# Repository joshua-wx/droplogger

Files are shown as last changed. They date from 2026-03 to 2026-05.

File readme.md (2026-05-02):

# Drop Logger — User Guide



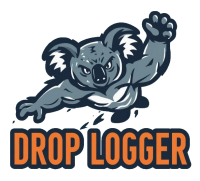
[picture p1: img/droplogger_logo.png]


## Table of Contents

- [Overview](#overview)
- [Power](#power)
- [Hardware Connections](#hardware-connections)
- [Sensor Specifications and Calibration](#sensor-specifications-and-calibration)
  - [BMP581 — Barometric Pressure](#bmp581--barometric-pressure)
  - [ICM20649 — Accelerometer and Gyroscope](#icm20649--accelerometer-and-gyroscope)
  - [ISM330DHCX — Accelerometer and Gyroscope](#ism330dhcx--accelerometer-and-gyroscope)
  - [Accelerometer Calibration](#accelerometer-calibration)
  - [Implications for Drop Experiments](#implications-for-drop-experiments)
- [Device Modes](#device-modes)
  - [Fall Detection](#fall-detection)
- [Data Logging](#data-logging)
  - [Starting a Log](#starting-a-log)
  - [Stopping a Log](#stopping-a-log)
  - [Output Files](#output-files)
  - [Binary File Format](#binary-file-format)
- [Downloading Data](#downloading-data)
  - [Option 1: WiFi File Server (Recommended)](#option-1-wifi-file-server-recommended)
  - [Option 2: USB (via serial tools)](#option-2-usb-via-serial-tools)
- [Converting Binary Files to CSV](#converting-binary-files-to-csv)
  - [CSV File Format](#csv-file-format)
- [Configuration](#configuration)
  - [Device Name](#device-name)
  - [IMU Selection](#imu-selection)
  - [Fall Detection Sensitivity](#fall-detection-sensitivity)
- [Code Overview — `drop_logger.py`](#code-overview--drop_loggerpy)
  - [Sensor Initialisation](#sensor-initialisation)
  - [The Logging Loop](#the-logging-loop)
  - [Key Variables You Might Want to Change](#key-variables-you-might-want-to-change)
- [File Structure Summary](#file-structure-summary)
- [Evaluating Data](#evaluating-data)
- [Python tests](#tests)
- [About](#about)
---

## Overview

The Drop Logger is an ESP32-S3-based data logger designed to record barometric pressure, acceleration, and gyroscope data at high frequency (approx every 3 ms). It uses two sensors over I2C:

- **BMP581** — barometric pressure sensor (records pressure difference from a reference taken at startup)
- **ICM20649** or **ISM330DHCX** — 6-axis accelerometer and gyroscope (records acceleration magnitude in m/s² and 3-axis rotation in °/s). The active IMU is selected via a config file — see [IMU Selection](#imu-selection).

The device is designed to be mounted inside a 3D-printed hailstone and dropped from a drone at heights of 100+ m. The recorded data allows characterisation of tumbling motions and fall dynamics of non-spherical hailstones.

The device logging is controlled entirely with the **Mode/Boot button** (GPIO 0) and provides feedback through an **onboard blue LED** (GPIO 2).

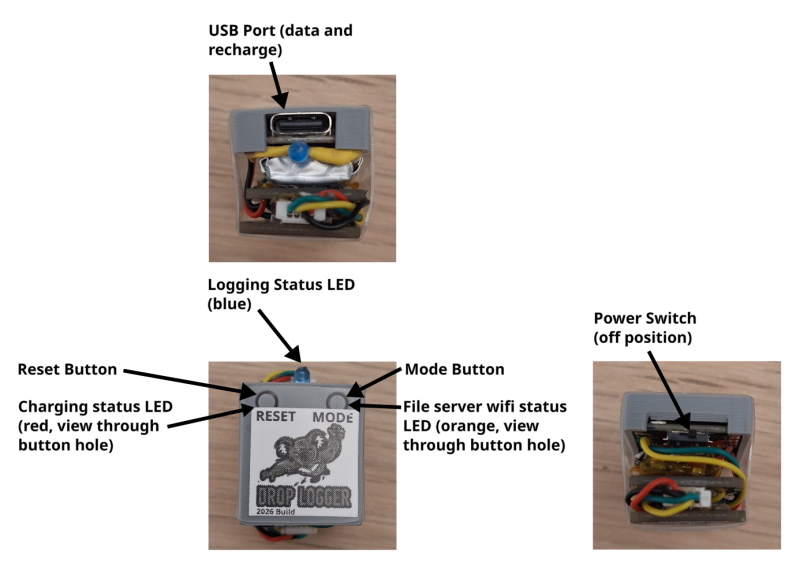
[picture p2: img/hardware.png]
hardware


---
## Power

The drop logger uses a permanently connected 3.7V 180mah lithium polymer battery. A fully charged battery will power the logger for at least 1 hour (e.g., 2-3 full flights).

To turn on the device, slide the switch towards the left side of the device (when viewing the logo from the front). The device will also be powered by usb regardless of the switch position.

To charge the battery, connect via usb when the power is switched on. A small red led will start flashing during charging and turn off when charging is completed. Charging takes approximately 1 hour to complete.

---

## Hardware Connections

| Component | ESP32-S3 Pin |
|---|---|
| I2C SCL | GPIO 6 |
| I2C SDA | GPIO 5 |
| BLUE LED | GPIO 2 |
| BOOT/MODE button | GPIO 0 |
| BMP581 address | 0x47 |
| ICM20649 address | 0x68 |
| ISM330DHCX address | 0x6A |

---

## Sensor Specifications and Calibration
  
### BMP581 — Barometric Pressure
 
The BMP581 is a 24-bit absolute barometric pressure sensor from Bosch Sensortec. It provides on-chip linearization and temperature compensation.
 
**Datasheet specifications:**
 
| Parameter | Value |
|---|---|
| Pressure operating range | 300–1250 hPa |
| Absolute accuracy (typical) | ±0.3 hPa (~±2.5 m altitude) |
| Absolute accuracy (max) | ±0.5 hPa (~±4 m altitude) |
| Relative accuracy (900-1100hPa) | ±0.4 Pa (~±0.033 m altitude) |
| Pressure resolution | 1/64 Pa (0.015625 Pa) |
| RMS noise (typical) | 0.08 Pa at 1000 hPa |
| Temperature coefficient offset | ±0.5 Pa/K (typical) |
| Long-term drift | ±0.1 hPa over 12 months |
| Temperature accuracy | ±0.5 °C |
| Maximum output data rate | up to 240 Hz (OSR×1) |
 
**Logger configuration:** The logger uses the fastest possible settings — OSR×1 for both pressure and temperature, with the IIR filter disabled (`COEF_0`). This maximises sample rate at the cost of higher per-sample noise. The noise specifications above are typical values; at OSR×1 with no filtering, individual samples will be noisier than the best-case figures. Higher oversampling (e.g. OSR×128) reduces noise dramatically but slows the output data rate.

### ICM20649 — Accelerometer and Gyroscope
 
The ICM20649 is a wide-range 6-axis MEMS inertial measurement unit from TDK InvenSense, designed for high-impact and high-speed rotation applications. It features a 16-bit ADC for each axis.
 
**Datasheet specifications:**
 
| Parameter | Value |
|---|---|
| Accelerometer full-scale ranges | ±4g, ±8g, ±16g, ±30g |
| Accelerometer sensitivity error | ±0.5% |
| Accelerometer noise density | 285 µg/√Hz |
| Gyroscope full-scale ranges | ±500, ±1000, ±2000, ±4000 °/s |
| Gyroscope sensitivity error | ±0.5% |
| Gyroscope noise density | 0.0175 °/s/√Hz |
| ADC resolution | 16-bit per axis |
| Operating temperature range | −40 to +85 °C |
 
**Logger configuration:** The accelerometer is set to ±8g and the gyroscope to ±4000 °/s. At the ±8g range, the raw sensitivity is 4096 LSB/g, giving a per-axis resolution of approximately 0.0024 m/s². At the ±4000 °/s gyroscope range, the sensitivity is 8.2 LSB/°/s, giving a resolution of approximately 0.12 °/s per axis. The ±8g accelerometer range is sufficient for freefall (~0g) through to aerodynamic deceleration, while the ±4000 °/s gyro range accommodates the fast tumbling expected during drop experiments.

### ISM330DHCX — Accelerometer and Gyroscope

The ISM330DHCX is a 6-axis MEMS IMU from STMicroelectronics. It is pin- and interface-compatible with the ICM20649 driver used in this project — the same `.acceleration` and `.gyro` properties are exposed, so no changes to the logging loop are required when switching between the two sensors.

**Datasheet specifications:**

| Parameter | Value |
|---|---|
| Accelerometer full-scale ranges | ±2g, ±4g, ±8g, ±16g |
| Accelerometer sensitivity error | ±1.5% |
| Accelerometer noise density | 70 µg/√Hz |
| Gyroscope full-scale ranges | ±125, ±250, ±500, ±1000, ±2000, ±4000 °/s |
| Gyroscope sensitivity error | ±1.5% |
| Gyroscope noise density | 0.007 °/s/√Hz |
| ADC resolution | 16-bit per axis |
| Operating temperature range | −40 to +105 °C |

**Logger configuration:** The accelerometer is set to ±8g and the gyroscope to ±4000 °/s at 208 Hz output data rate, matching the ICM20649 logging configuration. The `test_board.py` script uses ±1000 °/s for bench verification where fast rotation is unlikely.

### Accelerometer Calibration
 
The logger applies a simple scale correction to the acceleration magnitude to compensate for sensor bias. The correction factor is computed as:
 
```
accel_scale_correction = 9.80665 / a_mag_at_rest
```
 
where `a_mag_at_rest` is the measured acceleration magnitude when the sensor is stationary (currently set to 10.21 m/s² in `config/accel_calibration.txt`). The expected value at rest is 1g (9.80665 m/s²), so the correction factor (~0.960) scales all magnitude readings to compensate for the consistent offset. This is a first-order correction that assumes the bias is uniform across all axes and magnitudes. It does not correct for per-axis offset, cross-axis sensitivity, or nonlinearity.
 
**The value of `a_mag_at_rest` stored in `config/accel_calibration.txt` should be recalibrated for each individual sensor unit, as the offset varies from device to device.**
 
### Implications for Drop Experiments
 
For typical drop experiments from 100+ m, the key measurement considerations are:
 
**Pressure/altitude:** The relative accuracy of ±0.04 Pa (~±0.033 m) is more than adequate for tracking altitude changes of 100–250 m. However, the absolute accuracy of ±0.3 hPa (~±2.5 m) means the starting altitude cannot be determined to better than a few metres from pressure alone. The OSR×1 setting with no IIR filter means individual pressure samples will be noisy, but post-processing (e.g. a moving average) can smooth this out without affecting the overall altitude profile.
 
**Acceleration:** During freefall the sensor should read close to 0g (limited by aerodynamic drag on the hailstone). The ±8g range provides headroom for launch accelerations and impact events. The 0.01 m/s² recorded resolution is sufficient to distinguish freefall from rest.
 
**Gyroscope:** The ±4000 °/s range covers up to ~11 full rotations per second, which is expected to be sufficient for moderate tumbling. The 1 °/s integer resolution in the recorded data is adequate for characterising tumble rates and their evolution during the fall.

---

## Device Modes

On power-up the device enters a waiting state and continuously monitors the accelerometer. There are three ways to proceed:

| Trigger | Action | BLUE LED Feedback |
|---|---|---|
| **Fall detected** | Logging starts automatically | Blue LED on |
| **Short MODE button press** (<2 s) | Logging starts manually | Single flash, then Blue LED on |
| **Long MODE button press** (≥2 s) | WiFi file server starts | Blue LED blinks while held, then triple blink |

### Fall Detection

The device continuously reads the accelerometer and computes total acceleration magnitude (`√(aX² + aY² + aZ²)`). If this value drops below **5 m/s²** for **0.25 s**, the device assumes it is in freefall and starts logging automatically. This means you can power on the device before mounting it in the hailstone, and logging will begin on its own when dropped.

### Reset button

The reset button will restore the logger to the waiting state (but ideally do not use to terminate logging)

---

## Data Logging

### Duration

The total storage for data files is 5.8MB, which is approximately 24 minutes of data with the current binary encoding

### Starting a Log

Logging starts via any of the three triggers described above. Once running, the **Blue LED stays on** to indicate data is being recorded.

### Stopping a Log

Press the **MODE button** at any time to stop recording. The button is checked on every sample iteration:

1. **Press the MODE button** — recording stops immediately.
2. The **Blue LED turns off** and the serial console prints `Finished`.
3. The data file is flushed and closed.

Logging will also stop automatically if free storage drops below ~50 KB.
Frees space for storage is approximate 5.8 MB.

### Output Files

Data files are saved to the `/data/` directory on the ESP32's flash filesystem in binary format. Each run creates a new `.bin` file with an auto-incrementing number using the device name: `droplogger_1.bin`, `droplogger_2.bin`, etc. (or `{device_name}_1.bin` if you've changed the device name).

### Binary File Format

Each file uses the `DL01` binary format, consisting of a header followed by fixed-size data rows.

**Header (8 bytes):**

| Field | Type | Description |
|---|---|---|
| Magic | 4 bytes | `DL01` — format identifier |
| Reference pressure | float32 | Absolute pressure in hPa at startup |

**Row (16 bytes each):**

| Field | Type | Unit | Description |
|---|---|---|---|
| `time_ms` | uint32 | milliseconds | Elapsed time since logging started |
| `p_diff` | int32 | milli-hPa | `(ref_pressure − current_pressure) × 1000`. Positive values mean pressure has decreased (altitude increased). |
| `a_mag` | uint16 | centi-m/s² | Acceleration magnitude × 100 (`√(aX² + aY² + aZ²)`), with a scale correction applied |
| `gX` | int16 | °/s | Rotation rate around X axis (integer) |
| `gY` | int16 | °/s | Rotation rate around Y axis (integer) |
| `gZ` | int16 | °/s | Rotation rate around Z axis (integer) |

All values are big-endian. To reconstruct absolute pressure: `absolute_pressure = ref_pressure − (p_diff / 1000)`.

---

## Downloading Data

There are two ways to get data off the device: over WiFi using the built-in file server, or over USB.

### Option 1: WiFi File Server (Recommended, much much faster)

This is the easiest method and doesn't require any software on your computer beyond a web browser.
Make sure the PC/laptop is within 30 cm of the logger to get a good wifi signal (The logger has no wifi antenna...) 

1. **Power on** the device.
2. **Long-press the MODE button** (hold for ≥2 seconds). The Blue LED will blink while held and then triple-blink to confirm.
3. The device creates a **WiFi access point** named after the device (default: `droplogger`). The password is `hailstone`.
3. Orange LED under the MODE button will be activated.
4. **Connect your phone or laptop** to this WiFi network.
5. **Open a browser** and navigate to `http://192.168.4.1`.
6. You'll see a file listing page where you can **download** or **delete** individual files, or **delete all** files at once.

The device name (and therefore WiFi AP name) is read from `config/device_name.txt` on the ESP32's filesystem. See [Configuration](#configuration) for details.

### Option 2: USB (via serial tools, slow)

Connect to the ESP32-S3 over USB and use one of these tools:

- **Thonny IDE** — Connect to the board, navigate to `/data/` in the file browser, right-click a file and choose "Download to…".
- **mpremote** — `mpremote cp :/data/droplogger_1.bin .`
- **ampy** — `ampy --port /dev/ttyUSB0 get /data/droplogger_1.bin > droplogger_1.bin`

Replace the serial port (`/dev/ttyUSB0`, `COM3`, etc.) as appropriate for your system.

---

## Converting Binary Files to CSV

If you have `.bin` files from the logger (binary format, identified by the `DL01` magic header), you can convert them to CSV on your desktop computer using `unpack_droplogger_binary.py`. This is a standard Python script (not MicroPython) — run it on your PC. It does not require any non-standard Python libraries.

**Basic usage:**

```bash
python desktop-tools/unpack_droplogger_binary.py droplogger_1.bin
```

This produces `droplogger_1.csv` alongside the original file.

**Specify output path:**

```bash
python desktop-tools/unpack_droplogger_binary.py droplogger_1.bin -o output.csv
```

This produces `output.csv`.

**Batch convert a folder:**

```bash
python desktop-tools/unpack_droplogger_binary.py /path/to/folder/
python desktop-tools/unpack_droplogger_binary.py /path/to/folder/ --replace
```

This converts all .bin files in the directory.

### CSV File Format
 
Each output CSV contains a header row, a reference row, and then continuous data rows.
 
**Header:**
 
```
time(s),Pressure Difference(hPa),a(ms^-2),gX(deg/s),gY(deg/s),gZ(deg/s)
```
 
**Reference row:** The first data row has time set to `-0.001` and the second column contains the **absolute reference pressure** in hPa recorded at startup. The remaining columns are empty. This allows you to reconstruct absolute pressure from the differential values in subsequent rows: `absolute_pressure = ref_pressure − pressure_difference`.
 
**Data columns:**
 
| Column | Unit | Description |
|---|---|---|
| `time(s)` | seconds | Elapsed time since logging started (millisecond resolution) |
| `Pressure Difference(hPa)` | hPa | `ref_pressure − current_pressure`. Positive values mean pressure has decreased (altitude increased). |
| `a(ms^-2)` | m/s² | Acceleration magnitude (`√(aX² + aY² + aZ²)`), with scale correction applied |
| `gX(deg/s)` | °/s | Rotation rate around X axis (integer) |
| `gY(deg/s)` | °/s | Rotation rate around Y axis (integer) |
| `gZ(deg/s)` | °/s | Rotation rate around Z axis (integer) |
 
**Example:**
 
```
time(s),Pressure Difference(hPa),a(ms^-2),gX(deg/s),gY(deg/s),gZ(deg/s)
-0.001,1008.234,,,,
0.003,0.012,9.81,0,-1,2
0.006,0.025,9.78,1,0,1
0.009,0.041,9.83,-1,2,0
```
---

## Configuration

### Device Name

The device name is read from a file called `config/device_name.txt` on the ESP32's filesystem. If the file doesn't exist or is empty, the default name `droplogger` is used. This name is used for both the WiFi access point SSID and the binary file naming.

To change the device name, create or edit `config/device_name.txt` on the ESP32 (e.g. via Thonny or mpremote):

```
my-hailstone-1
```

### IMU Selection

The IMU type is read from `config/imu_type.txt` on the ESP32's filesystem. If the file is missing or contains an unrecognised value, the device defaults to `ICM20649`.

To select the ISM330DHCX, create `config/imu_type.txt` containing:

```
ISM330DHCX
```

To revert to the ICM20649, set the file contents to:

```
ICM20649
```

An example file is provided at `config/imu_type.txt.example`. The same setting is read by `main.py`, `drop_logger.py`, and `test_board.py`, so only one file needs to be updated.

### Fall Detection Sensitivity

In `main.py`, these variables control the automatic fall trigger:

```python
fall_trigger_counter_limit = 5    # consecutive low-g readings required (note: 0.05s between readings)
fall_trigger_a_threshold = 5      # m/s² — readings below this count as freefall
```

Lowering the threshold or increasing the counter limit makes fall detection less sensitive (fewer false triggers). Raising the threshold or lowering the limit makes it more sensitive.

---

## Code Overview — `drop_logger.py`

This section walks through the main logging script for anyone wanting to modify it.

### Sensor Initialisation

The `main()` function sets up both sensors on a shared I2C bus:

- **ICM20649 or ISM330DHCX** — selected via `config/imu_type.txt` (see [IMU Selection](#imu-selection)). Both are configured with a gyro range of ±4,000 °/s to capture fast rotations without clipping. The ISM330DHCX additionally has its output data rate set to 208 Hz.
- **BMP581** is configured for speed over precision: 1× oversampling on both pressure and temperature, no IIR filtering (`COEF_0`). This gives the fastest possible sample rate at the cost of some noise.

A "burn" read (`_ = bmp.pressure`) discards the first pressure measurement after power-on, which can be unreliable. The second read is saved as the reference pressure.

An accelerometer scale correction factor is applied to compensate for sensor bias: `accel_scale_correction = 9.80665 / a_mag_at_rest` where `a_mag_at_rest` is the measured magnitude when stationary and set in `config/accel_calibration` (default is `10.21 m/s²`).

### The Logging Loop

The core loop runs as fast as the I2C reads allow (no explicit delay):

1. **Read pressure** and compute the difference from the reference.
2. **Read acceleration** — 3-axis values are read and combined into a single magnitude (`√(aX² + aY² + aZ²)`), then scale-corrected.
3. **Read gyroscope** — 3-axis values in °/s (written as integers).
4. **Timestamp** using `utime.ticks_us()` for microsecond resolution (stored as milliseconds).
5. **Pack and write** a binary row to the open file.

The MODE button is checked on every iteration and will immediately stop recording if pressed. Every 500 rows the file buffer is flushed to flash storage and available disk space is checked.

---

## File Structure Summary

**Firmware** (`logger-scripts/` — deployed to the ESP32):

| File | Role |
|---|---|
| `main.py` | Entry point — fall detection, button handling, launches logger or file server |
| `drop_logger.py` | Core high-speed sensor logging to binary |
| `file_server.py` | WiFi access point and HTTP file server for downloading/deleting data |
| `test_board.py` | Simple sensor test script — reads and prints pressure, accel, and gyro at 10 Hz for board verification |
| `accel_calibration.py` | Compute and store accelerometer rest magnitude (1000-sample mean) in `config/accel_calibration.txt` |
| `bmpxxx.py` | MicroPython driver for BMP581/585/390/280/BME280 pressure sensors |
| `icm20649.py` | MicroPython driver for ICM20649 accelerometer/gyroscope |
| `ism330dhcx.py` | MicroPython driver for ISM330DHCX accelerometer/gyroscope |
| `i2c_helpers.py` | Low-level I2C register read/write utilities used by the BMP driver |
| `boot.py` | MicroPython boot file (default, mostly empty) |

**Desktop tools** (`desktop-tools/` — run on your PC):

| File | Role |
|---|---|
| `unpack_droplogger_binary.py` | Converts binary `.bin` log files to CSV |
| `evaluate_droplogger.ipynb` | Jupyter notebook for evaluating downloaded CSV data |
| `sample-data/` | Sample drop test dataset for use with the notebook |
| `requirements.txt` | Python dependencies for desktop tools |

**3D models** (`models/` — printable enclosure parts):

| File | Role |
|---|---|
| `droplogger_body.stl` | Main enclosure body |
| `droplogger_top.stl` | Enclosure lid |
| `droplogger_pin.stl` | Retention pin |
| `droplogger_model.step` | STEP file for CAD editing |
| `models_readme.md` | Assembly and printing notes |

---

## Evaluating Data

Once you have a CSV file (converted from binary using `unpack_droplogger_binary.py`), the Jupyter notebook `desktop-tools/evaluate_droplogger.ipynb` provides a ready-made workflow for inspecting a drop test. It covers:

- **Timing** — median / maximum sample interval and write-pause detection
- **Channel statistics** — min, max, mean, std for pressure, acceleration and all gyro axes
- **Time-series plots** — pressure, acceleration and rotation on a shared time axis
- **Instantaneous sample rate** — visualises write-flush pauses
- **Sensor saturation check** — flags gyro samples near the ±4000 °/s hardware limit
- **Terminal velocity** — detects the pressure plateau during freefall
- **Tumble frequency (PSD)** — Welch power spectral density of gyro channels during freefall
- **Pressure noise floor** — sensor noise measured during the post-landing stationary phase
- **Write-pause impact** — checks for stale sensor values around write-flush pauses

A sample dataset is included in `desktop-tools/sample-data/` so you can run the notebook straight away.

```bash
# Install dependencies
pip install -r desktop-tools/requirements.txt

# Launch Jupyter from the desktop-tools directory
cd desktop-tools
jupyter notebook evaluate_droplogger.ipynb
```

## Testing New Boards

When assembling or commissioning a new logger board, use `test_board.py` to verify that both sensors are functioning correctly. This script runs a simple loop that reads pressure, accelerometer, and gyroscope data and prints them to the console at 10 Hz (every 0.1 seconds).

For accelerometer bias calibration, use `accel_calibration.py` which captures 1000 samples at rest and writes the mean magnitude to `config/accel_calibration.txt`.

**To run the test:**

1. Copy `test_board.py` to the ESP32 (e.g. via Thonny, mpremote, or the file server).
2. Open a serial monitor or terminal connected to the board (115200 baud).
3. Run the script: In Thonny, right-click and choose "Run", or execute `import test_board` in the REPL.
4. You should see continuous output like:
   ```
   Initializing ICM20649...
   ✓ ICM20649 initialized
   Initializing BMP581...
   ✓ BMP581 initialized
   
   Starting sensor readings (0.1s interval, Ctrl+C to stop)...
   
   Pressure: 1008.34 hPa  |  Accel: (   0.12,   -0.05,   10.21) m/s²  |  Gyro: (  -0.2,    0.1,    0.3) deg/s
   Pressure: 1008.34 hPa  |  Accel: (   0.08,    0.02,   10.19) m/s²  |  Gyro: (   0.1,   -0.2,    0.0) deg/s
   ```
5. Check that:
   - Both sensors initialize successfully (no error messages)
   - Pressure readings are within 300–1250 hPa (typical sea-level value ~1010 hPa)
   - Accelerometer reads close to 10 m/s² on the Z-axis when stationary (Earth's gravity = 9.81 m/s²)
   - Gyroscope reads near zero when stationary
   - All values update continuously without freezing or errors
6. Press **Ctrl+C** in the terminal to stop the test.

The IMU name printed during initialisation reflects whichever sensor is selected in `config/imu_type.txt` (defaults to ICM20649 if the file is absent).

If either sensor fails to initialize, check I2C connections and sensor addresses (BMP581 at 0x47, ICM20649 at 0x68, ISM330DHCX at 0x6A).

---

## Tests

Unit tests are provided for the three desktop-relevant scripts (`drop_logger.py`, `main.py`, and `unpack_droplogger_binary.py`) in the `tests/` directory. The tests cover binary format correctness, sensor data encoding, file naming, calibration fallback, fall detection logic, and button-press handling. Hardware dependencies (I2C, BMP581, ICM20649, MicroPython-specific modules) are replaced with mocks so the tests run on a standard desktop Python installation.

```bash
# Install dependencies
pip install -r requirements-dev.txt

# Run tests from the project root
python -m pytest tests/ -v
```

## About
This project was built with the assistance of Anthropic's Claude.
For questions or problems, please raise an issue in the github issue tracker.

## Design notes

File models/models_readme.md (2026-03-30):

### Model Files

_A collection of model files are provided to help integrate the drop logger into hailstone models._

These parts consist of
- 50 mm diameter hemisphere to enclose the logger
- 3 mm diameter pins (6mm length) to  close the hemispheres
- Top cover for Seeed Xiao EPS32-S3 to allow easy access to buttons.

With two hemispheres, the cavity for the logger is: 33 mm long, 22 mm wide and 25 mm high

The hemispheres are held together using:
- 2x 3D printed pins that occupy two pairs of slots
- 2x pairs of 6mm wide x 3mm high neodymium magnets (cylinder shape) that use the remaining two pairs of slots.
- Epoxy glue is ideally used to secure magnets.

Parts are provided as a CAD file (.stl) for integration with hail models and 3D printing mesh files (.stl).

Integration into a hailstone model requires:
1. Selecting hailstone models which can fit a 50 mm diameter sphere
2. Marking the centre of mass (CoM) for the model
3. Remove a 50 mm sphere from the hailstone centred at the CoM.
3. Slicing the hailstone model on the Dmax-Dint axis, through the CoM
4. Inserting a droplogger hemisphere in each cavity.
5. Add pins and magnets to each hailstone half.

Test drops used tough PLA+ printed with 40% fill (and orientated so cavity and pin slots need no supports).

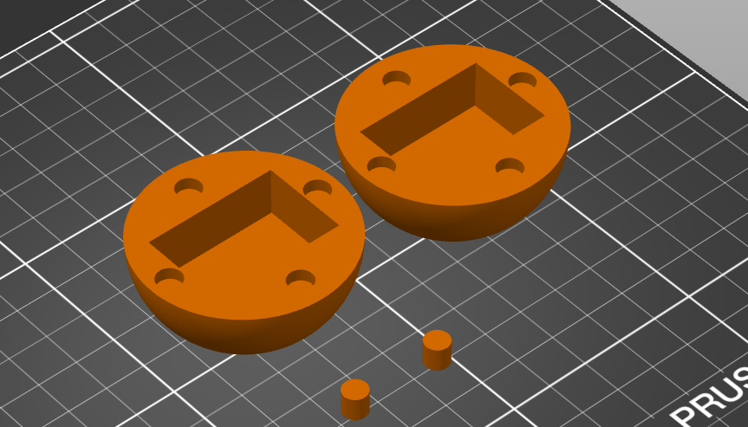
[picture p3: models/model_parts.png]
model_image


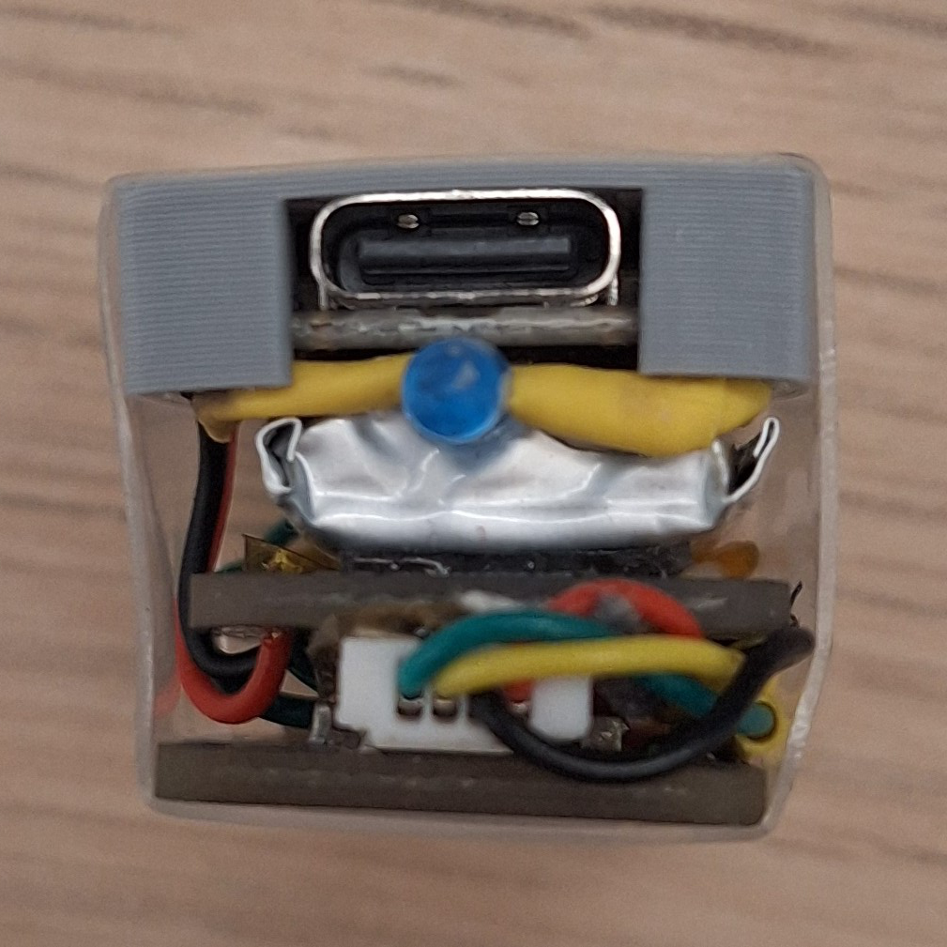
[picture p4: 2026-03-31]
img/front_view.jpg

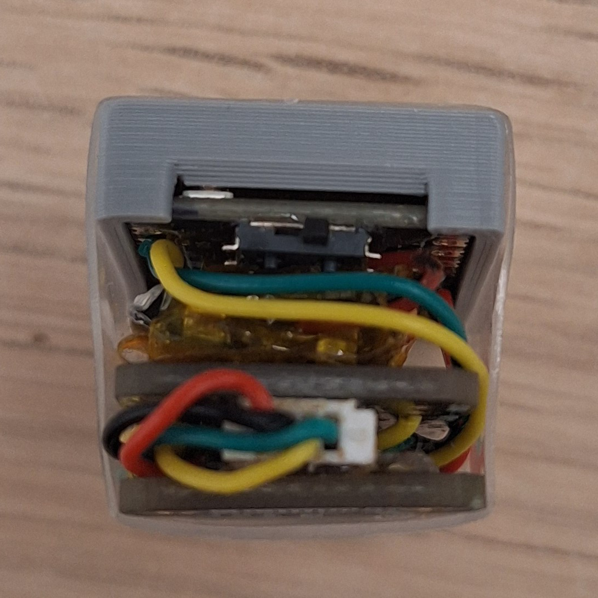
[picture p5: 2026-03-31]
img/back_view.jpg

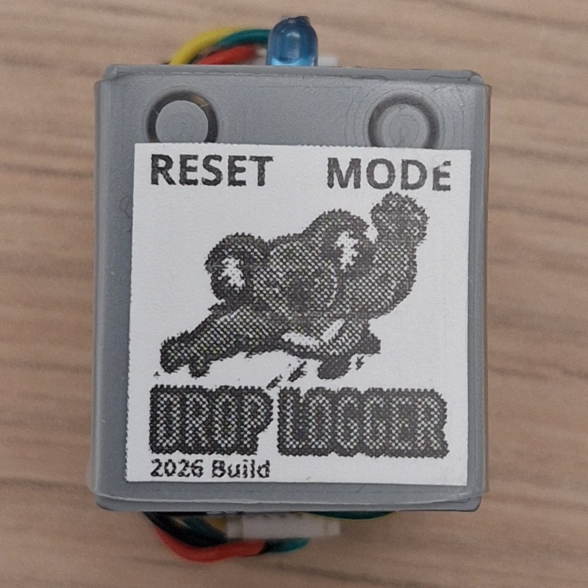
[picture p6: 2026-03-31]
img/top_view.jpg

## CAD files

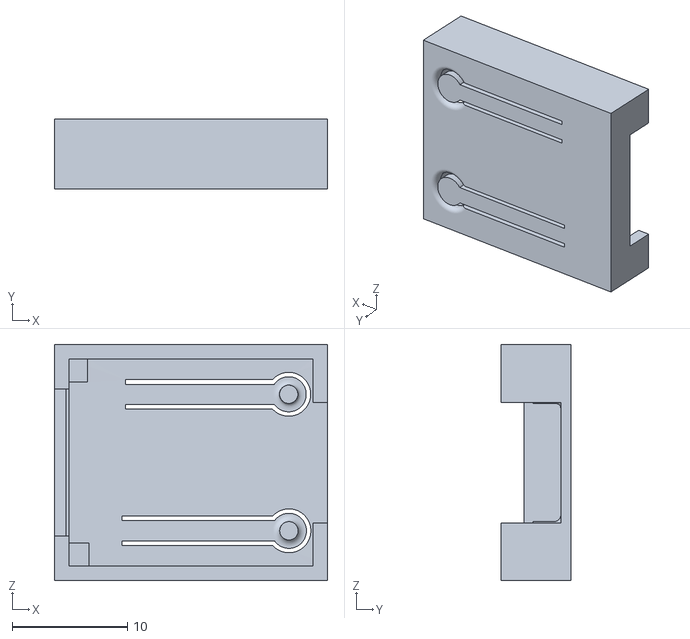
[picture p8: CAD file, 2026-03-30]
models/droplogger_top.stl
23.7 x 6.11 x 20.5

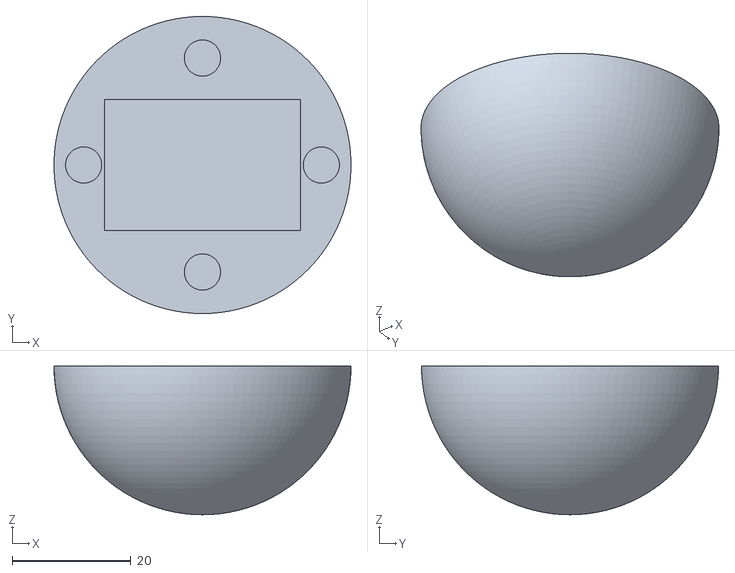
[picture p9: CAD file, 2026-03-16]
models/droplogger_body.stl
50.0 x 50.0 x 25.0

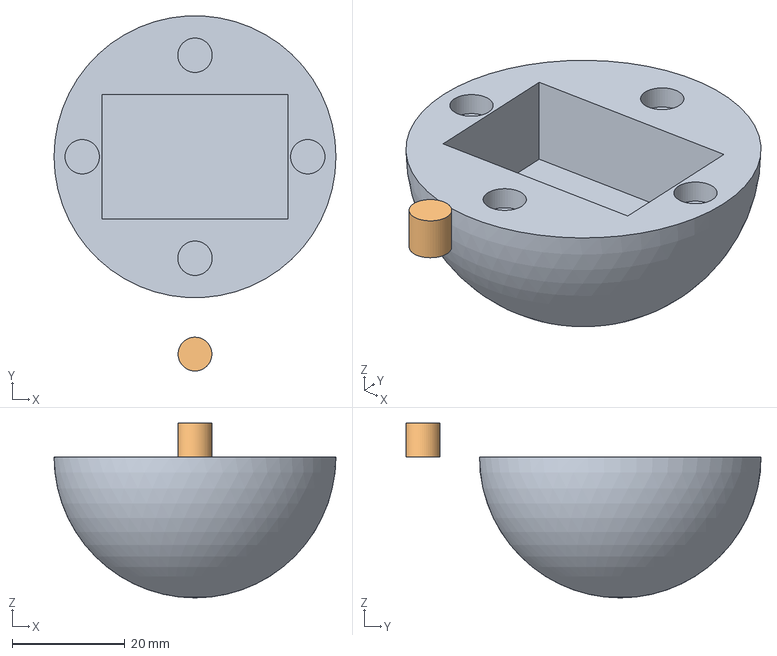
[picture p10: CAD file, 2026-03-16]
models/droplogger_model.step
50.0 x 63.0 x 31.0 mm

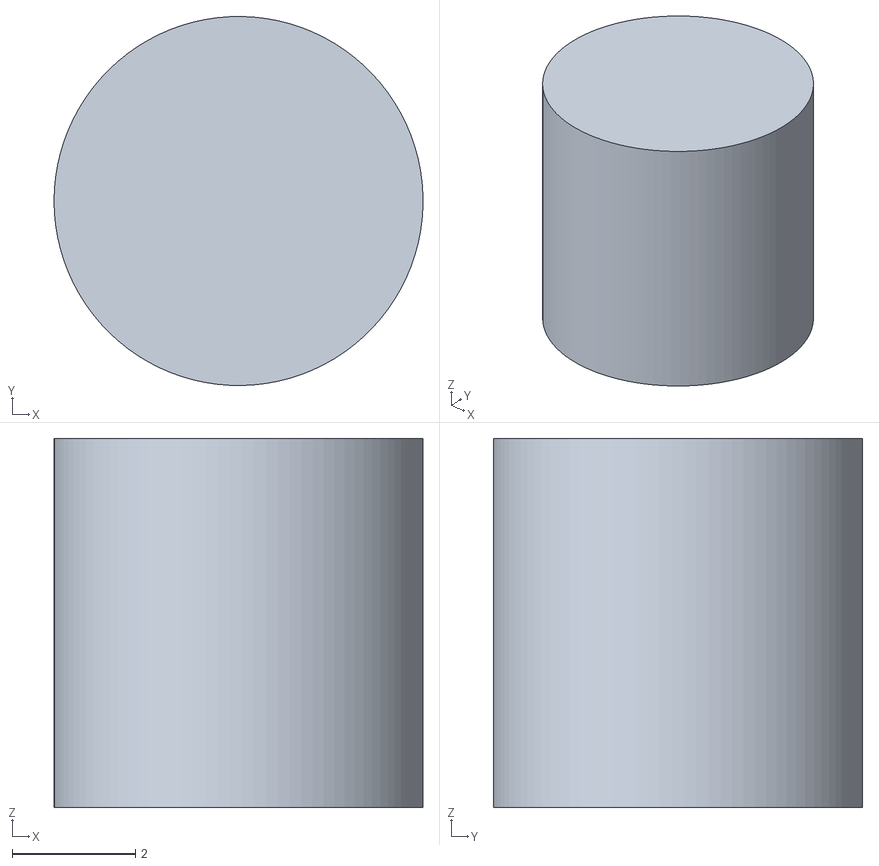
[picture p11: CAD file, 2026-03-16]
models/droplogger_pin.stl
6.00 x 6.00 x 6.00

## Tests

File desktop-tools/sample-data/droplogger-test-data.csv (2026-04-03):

time(s) | Pressure Difference(hPa) | a(ms^-2) | gX(deg/s) | gY(deg/s) | gZ(deg/s)
-0.001 | 1009.621
0.004 | -0.008 | 0.81 | -54 | 203 | -77
0.007 | -0.012 | 0.81 | -54 | 203 | -77
0.01 | -0.009 | 0.81 | -54 | 203 | -77
0.013 | -0.016 | 0.81 | -52 | 190 | -75
0.016 | -0.016 | 0.81 | -52 | 190 | -75
0.019 | -0.023 | 0.81 | -52 | 190 | -75
0.022 | -0.023 | 0.84 | -50 | 176 | -72
0.025 | -0.028 | 0.84 | -50 | 176 | -72
0.097 | -0.074 | 1.04 | -37 | 77 | -53
0.1 | -0.057 | 1.04 | -37 | 77 | -53
0.103 | -0.057 | 1.04 | -35 | 61 | -51
0.106 | -0.058 | 1.04 | -35 | 61 | -51
0.109 | -0.045 | 1.04 | -35 | 61 | -51
0.112 | -0.045 | 1.04 | -32 | 45 | -48
0.115 | -0.051 | 1.23 | -32 | 45 | -48
0.118 | -0.054 | 1.23 | -32 | 45 | -48
0.123 | -0.056 | 1.23 | -30 | 29 | -45
0.131 | -0.044 | 1.23 | -28 | 13 | -42
0.135 | -0.055 | 1.17 | -28 | 13 | -42
0.138 | -0.067 | 1.17 | -28 | 13 | -42
0.141 | -0.067 | 1.17 | -26 | -3 | -41
0.144 | -0.062 | 1.17 | -26 | -3 | -41
0.147 | -0.071 | 1.17 | -26 | -3 | -41
0.15 | -0.085 | 1.17 | -24 | -19 | -39
0.154 | -0.102 | 1.04 | -24 | -19 | -39
0.158 | -0.102 | 1.04 | -24 | -19 | -39
0.161 | -0.09 | 1.04 | -22 | -35 | -36
0.164 | -0.091 | 1.04 | -22 | -35 | -36
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

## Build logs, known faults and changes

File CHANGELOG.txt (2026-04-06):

Droplogger
CHANGELOG.txt
--------------------------

7 April 2026 — v1.2.1
* Fixed unpacker script and updated test data
* Corrected user LED pin in file_server.py

3 April 2026 — v1.2.0
* Added accel_calibration.py script for automated accelerometer calibration (1000-sample mean)
* Added test_board.py script for sensor verification during board commissioning
* Updated README with 'Testing New Boards' section and usage guide

3 April 2026 — v1.1.1
* Added test_board.py script for sensor verification during board commissioning
* Updated README with 'Testing New Boards' section and usage guide

2 April 2026 — v1.1.0
* Added unit tests for drop_logger.py, main.py and unpack_droplogger_binary.py
* Added .gitignore
* Added requirements-dev.txt (pytest)
* Renamed scripts/ to logger-scripts/ and moved unpack_droplogger_binary.py to desktop-tools/
* Added .example files for device-specific config (device_name.txt, accel_calibration.txt)
* Added data evaluation Jupyter notebook (desktop-tools/evaluate_droplogger.ipynb) with:
  - Timing statistics and write-pause detection
  - Per-channel statistics (min/max/mean/std)
  - Time-series plots (pressure, acceleration, rotation)
  - Instantaneous sample rate plot
  - Sensor saturation check
  - Terminal velocity detection
  - Tumble frequency PSD
  - Pressure noise floor measurement
  - Write-pause stale-value check
* Added sample drop test dataset (desktop-tools/sample-data/)
* Added desktop-tools/requirements.txt (pandas, matplotlib, numpy, scipy, jupyter)
* Updated README with tests section and revised file structure

17 March 2026
* Added config file for device name

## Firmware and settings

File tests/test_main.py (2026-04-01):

"""
Tests for main.py

main.py is MicroPython firmware whose top-level code runs an infinite
while-loop the moment the module is imported.  To make it testable we:

  1. Replace all hardware modules in sys.modules before each import.
  2. Configure the ICM20649 mock so that the fall-detection break condition
     fires after exactly five loop iterations (acceleration below threshold).
  3. Mock drop_logger.main() so the logger itself does not run.

Each test deletes 'main' from sys.modules before importing so the
module-level code executes fresh with the desired mock configuration.

Limitations
-----------
The nested button-press blink loop (short vs long press) is tested by
carefully staging the sequence of boot_pin.value() return values and the
simulated elapsed time returned by time.ticks_diff().  Because all of this
state is controlled via mock side-effects the tests are somewhat sensitive
to the exact call order; if main.py's button-handling logic changes the
tests may need corresponding updates.
"""
import sys
import os
import importlib
from unittest.mock import MagicMock, call
import pytest

# conftest.py already adds scripts/ to sys.path


# ---------------------------------------------------------------------------
# Mock-setup helpers
# ---------------------------------------------------------------------------

def _install_mocks(acceleration=(0.0, 0.0, 0.0), boot_pin_values=None,
                   ticks_diff_value=100):
    """Install all module-level mocks required by main.py.

    Parameters
    ----------
    acceleration:
        Value returned by icm.acceleration on every loop iteration.
        (0, 0, 0) → a_total = 0 < threshold → fall detected after 5 iters.
        (9.81, 0, 0) → a_total ≈ 9.81 > threshold → no fall detection.
    boot_pin_values:
        Optional list used as side_effect for boot_pin.value().
        None → always returns 1 (not pressed).
    ticks_diff_value:
        Return value of time.ticks_diff(); controls short vs long press.
    """
    # Remove previously imported main so the loop re-runs cleanly
    sys.modules.pop("main", None)

    # ICM20649 instance
    icm_instance = MagicMock()
    icm_instance.acceleration = acceleration

    icm20649_mock = MagicMock()
    icm20649_mock.ICM20649.return_value = icm_instance

    # Boot-pin (GPIO 0)
    boot_pin = MagicMock()
    if boot_pin_values is not None:
        boot_pin.value.side_effect = boot_pin_values
    else:
        boot_pin.value.return_value = 1  # never pressed

    def pin_factory(pin_num, *args, **kwargs):
        return boot_pin if pin_num == 0 else MagicMock()

    machine_mock = MagicMock()
    machine_mock.Pin.side_effect = pin_factory

    # time mock — ticks_ms/ticks_diff are MicroPython extensions not in
    # standard library; mocking the whole module avoids AttributeError
    time_mock = MagicMock()
    time_mock.ticks_ms.return_value = 0
    time_mock.ticks_diff.return_value = ticks_diff_value
    time_mock.sleep = MagicMock()

    drop_logger_mock = MagicMock()
    file_server_mock = MagicMock()

    sys.modules["machine"] = machine_mock
    sys.modules["icm20649"] = icm20649_mock
    sys.modules["time"] = time_mock
    sys.modules["drop_logger"] = drop_logger_mock
    sys.modules["file_server"] = file_server_mock

    return {
        "machine": machine_mock,
        "icm": icm_instance,
        "icm20649": icm20649_mock,
        "boot_pin": boot_pin,
        "time": time_mock,
        "drop_logger": drop_logger_mock,
        "file_server": file_server_mock,
    }


def _run_main():
    """Import (re-import) main.py, executing its module-level loop."""
    import main  # noqa: F401
    return sys.modules["main"]


# ---------------------------------------------------------------------------
# Fall-detection tests
# ---------------------------------------------------------------------------

class TestFallDetection:

    def test_fall_triggers_drop_logger(self, tmp_path, monkeypatch):
        """Sustained low acceleration for ≥ fall_trigger_counter_limit
        iterations must call drop_logger.main()."""
        monkeypatch.chdir(tmp_path)
        # a_total = 0.0 < fall_trigger_a_threshold (5) → counter increments
        mocks = _install_mocks(acceleration=(0.0, 0.0, 0.0))

        _run_main()

        mocks["drop_logger"].main.assert_called_once()

    def test_fall_passes_device_name_from_config(self, tmp_path, monkeypatch):
        """drop_logger.main() must receive the name read from device_name.txt."""
        monkeypatch.chdir(tmp_path)
        (tmp_path / "config").mkdir()
        (tmp_path / "config" / "device_name.txt").write_text("my-sensor")

        mocks = _install_mocks(acceleration=(0.0, 0.0, 0.0))

        _run_main()

        mocks["drop_logger"].main.assert_called_once_with("my-sensor")

    def test_fall_uses_default_device_name_when_config_missing(self, tmp_path, monkeypatch):
        """When device_name.txt is absent drop_logger.main() receives
        the hard-coded fallback name 'droplogger'."""
        monkeypatch.chdir(tmp_path)
        mocks = _install_mocks(acceleration=(0.0, 0.0, 0.0))

        _run_main()

        mocks["drop_logger"].main.assert_called_once_with("droplogger")

    def test_fall_counter_resets_after_high_acceleration(self, tmp_path, monkeypatch):
        """If a high-acceleration sample interrupts the sequence the counter
        must reset; the logger should only start after 5 *consecutive* low
        readings."""
        monkeypatch.chdir(tmp_path)

        # 4 low → counter = 4; 1 high → counter resets to 0;
        # 5 low → counter = 5 → fall triggered
        readings = (
            [(0.0, 0.0, 0.0)] * 4    # 4 consecutive low
            + [(9.81, 0.0, 0.0)]      # interrupt: counter reset
            + [(0.0, 0.0, 0.0)] * 5  # 5 consecutive low → triggers
        )

        mocks = _install_mocks()
        # Drive icm.acceleration from the readings list
        mocks["icm"].acceleration = readings[0]
        idx = [0]

        class _AccelDescriptor:
            def __get__(self, obj, objtype=None):
                v = readings[idx[0]] if idx[0] < len(readings) else readings[-1]
                idx[0] += 1
                return v

        type(mocks["icm"]).acceleration = _AccelDescriptor()

        _run_main()

        mocks["drop_logger"].main.assert_called_once()


# ---------------------------------------------------------------------------
# Button-press tests
# ---------------------------------------------------------------------------

class TestButtonPress:

    def test_short_press_triggers_drop_logger(self, tmp_path, monkeypatch):
        """A button press held for less than LONG_PRESS_MS (2000 ms) must
        call drop_logger.main()."""
        monkeypatch.chdir(tmp_path)

        # High acceleration keeps fall-detection inactive.
        # boot_pin sequence:
        #   call 1 – outer loop "if boot_pin.value() == 0" → 0 (pressed)
        #   call 2 – blink-loop "while boot_pin.value() == 0" → 0 (still held)
        #   call 3 – blink-loop → 1 (released)
        # ticks_diff → 100 ms < LONG_PRESS_MS (2000) → short press
        mocks = _install_mocks(
            acceleration=(9.81, 0.0, 0.0),
            boot_pin_values=[0, 0, 1],
            ticks_diff_value=100,
        )

        _run_main()

        mocks["drop_logger"].main.assert_called_once()
        mocks["file_server"].start_ap.assert_not_called()

    def test_long_press_starts_file_server(self, tmp_path, monkeypatch):
        """A button press held for ≥ LONG_PRESS_MS (2000 ms) must call
        file_server.start_ap() with the device name as the SSID."""
        monkeypatch.chdir(tmp_path)

        # boot_pin sequence:
        #   call 1 – outer loop → 0 (pressed)
        #   call 2 – blink-loop → 0 (held, first iteration)
        #   call 3 – blink-loop → 0 (held, second iteration)
        #   call 4 – blink-loop → 1 (released)
        # ticks_diff → 2100 ms ≥ LONG_PRESS_MS → long press
        mocks = _install_mocks(
            acceleration=(9.81, 0.0, 0.0),
            boot_pin_values=[0, 0, 0, 1],
            ticks_diff_value=2100,
        )

        _run_main()

        mocks["file_server"].start_ap.assert_called_once_with(
            ssid="droplogger", password="hailstone"
        )
        mocks["drop_logger"].main.assert_not_called()

    def test_long_press_uses_device_name_from_config(self, tmp_path, monkeypatch):
        """The SSID passed to file_server.start_ap() should match the name
        read from device_name.txt."""
        monkeypatch.chdir(tmp_path)
        (tmp_path / "config").mkdir()
        (tmp_path / "config" / "device_name.txt").write_text("drop-unit-7")

        mocks = _install_mocks(
            acceleration=(9.81, 0.0, 0.0),
            boot_pin_values=[0, 0, 0, 1],
            ticks_diff_value=2100,
        )

        _run_main()

        mocks["file_server"].start_ap.assert_called_once_with(
            ssid="drop-unit-7", password="hailstone"
        )

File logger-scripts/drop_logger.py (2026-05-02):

import os
import time
import utime
import machine
from math import sqrt
import struct
from machine import Pin, I2C
# pressure sensor library
from bmpxxx import BMP581

try:
    with open('config/imu_type.txt', 'r') as f:
        IMU_TYPE = f.read().strip()
    if IMU_TYPE not in ('ICM20649', 'ISM330DHCX'):
        IMU_TYPE = 'ICM20649'
except OSError:
    IMU_TYPE = 'ICM20649'

if IMU_TYPE == 'ICM20649':
    import icm20649
elif IMU_TYPE == 'ISM330DHCX':
    import ism330dhcx

#set verbose for debugging
verbose = False
#set storage checks (but will create small delays)
check_storage = False

#default acceleration value
default_a_mag_at_rest = 10.21

# Binary format constants
FILE_MAGIC = b'DL01'       # download logger v1 format identifier
HEADER_FORMAT = '>4sf'     # magic(4s), ref_pressure(f)
HEADER_SIZE = struct.calcsize(HEADER_FORMAT)  # 8 bytes
ROW_FORMAT = '>IiHhhh'    # time_ms(I), p_diff(i), a_mag(H), gX(h), gY(h), gZ(h)
ROW_SIZE = struct.calcsize(ROW_FORMAT)        # 16 bytes

# Encoding:
#   time      : uint32 milliseconds since start (max ~49 days)
#   pressure  : int32  milli-hPa difference from ref (±2,147,483 hPa, covers ±2000m+)
#   accel     : uint16 magnitude × 100 (max 655 m/s² ≈ 66g, covers ±16g)
#   gyro  x3  : int16  deg/s as integer (±32767, covers ±4000)

def count_files(path, extension):
    #check the number of data files in a directory
    return sum(1 for f in os.listdir(path) if f.endswith(extension))

def main(device_name='droplogger-test'):
    print('Logger software activated')

    #acceleration correction
    try:
        with open('config/accel_calibration.txt', 'r') as f:
            a_mag_at_rest = float(f.read().strip())
            print('accel_calibration read successful')
        if not a_mag_at_rest:
            a_mag_at_rest = default_a_mag_at_rest
    except OSError:
        a_mag_at_rest = default_a_mag_at_rest
    accel_scale_correction = 9.80665 / a_mag_at_rest
    print('accelerometer reference', a_mag_at_rest, 'm/s/s')

    # The BOOT button is connected to GPIO 0 on the ESP32-S3. Use to stop logging
    boot_pin = Pin(0, Pin.IN, Pin.PULL_UP)
    
    #init led
    led = Pin(2, Pin.OUT)
    led.value(0)  # Turn the LED OFF

    # Accelerometer/Gyro
    i2c = I2C(scl=Pin(6), sda=Pin(5))
    if IMU_TYPE == 'ICM20649':
        icm = icm20649.ICM20649(i2c, address=0x68)
        icm.gyro_range = icm20649.GyroRange.RANGE_4000_DPS
    elif IMU_TYPE == 'ISM330DHCX':
        icm = ism330dhcx.ISM330DHCX(i2c, address=0x6A)
        icm.accelerometer_range     = ism330dhcx.AccelRange.RANGE_8G
        icm.gyro_range              = ism330dhcx.GyroRange.RANGE_4000_DPS
        icm.accelerometer_data_rate = ism330dhcx.Rate.RATE_208_HZ
        icm.gyro_data_rate          = ism330dhcx.Rate.RATE_208_HZ
    
    #Barometer (BMP581)
    bmp = BMP581(i2c, address=0x47)
    bmp.pressure_oversample_rate = bmp.OSR1   # 1x oversampling
    bmp.temperature_oversample_rate = bmp.OSR1  # 1x oversampling
    bmp.iir_coefficient = bmp.COEF_0  # No filtering
        
    # Oddly first pressure measure after power-on return wrong value.
    # so we "burn" one measure
    _ = bmp.pressure
    #get a reference pressure to improve compression
    ref_pressure = bmp.pressure #hPa
    
    # Change filename and fileformat here.
    next_file_int = count_files('/data', '.bin') + 1
    filename = f"data/{device_name}_{next_file_int}.bin"

    # Save file in path /
    print('Start logging')
    write_count = 0
    with open(filename, "a") as f:
        # Write header
        header = struct.pack(HEADER_FORMAT, FILE_MAGIC, ref_pressure)
        f.write(header)
        start_time = utime.ticks_ms()
        led.value(1)
        while True:
            #read new data
            pressure_diff = ref_pressure-bmp.pressure #hPa
            ax, ay, az = icm.acceleration # read the accelerometer [ms^-2]
            a_mag = sqrt(ax * ax + ay * ay + az * az)
            a_mag *= accel_scale_correction #correct for sensor bias
            gx, gy, gz = icm.gyro   # read the gyro [deg/s]
            
            #time of obs
            elapsed_ms = utime.ticks_diff(utime.ticks_ms(), start_time)
            
            # Pack and write row
            row = struct.pack(ROW_FORMAT,
                elapsed_ms,
                int(round(pressure_diff * 1000)),  # milli-hPa
                int(round(a_mag * 100)),            # centi-m/s²
                int(round(gx)),                     # deg/s
                int(round(gy)),
                int(round(gz)),
            )
            f.write(row)
            write_count += 1
            #write_count += 1
            if verbose:
                print('NEW data')
                print(f"t={elapsed_ms}ms p={pressure_diff:.3f} a={a_mag:.2f} g=({gx},{gy},{gz})")
                print('')
            #kill loop if boot pin is pressed
            if boot_pin.value() == 0:
                print('stopping logging manually')
                #flush cache
                f.flush()
                break
            #run checks
            if write_count == 500:
                #flush cache
                f.flush()
                #reset counter
                write_count = 0
                #check storage
                if check_storage:
                    stat = os.statvfs('/data')
                    free_bytes = stat[0] * stat[3]  # block_size * free_blocks
                    if free_bytes < 50_000:  # ~50KB safety margin
                        print('aborting due to storage limits')
                        break
                    else:
                        print('storage now at', free_bytes)
    print('Finished')
    #turn off led
    led.value(0)

    #restart device
    machine.reset()
    
if __name__ == "__main__":
    main()    
#todo:
#test without blocking pressure sensor...
#test S3 and multi threading to reduce time spent writting.

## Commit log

2026-03-16 models to folder
    [droplogger_body.stl, droplogger_model.step, droplogger_pin.stl]
2026-03-17 device name config
2026-03-29 S3 support
    [seeed-top.3mf]
2026-03-29 added section on sensor specs
2026-03-30 power info
2026-03-31 reset after program finished
    [drop_logger.py]
2026-03-31 power info added
2026-04-01 Add unit tests for drop_logger, main, and unpack scripts
    - tests/conftest.py: adds scripts/ to sys.path
    - tests/test_drop_logger.py: 18 tests covering count_files, binary
    format constants, and main() with hardware mocked
    - tests/test_main.py: 7 tests covering fall detection and button-press
    logic (short and long press) via fresh module import per test
    - tests/test_unpack_droplogger_binary.py: 24 tests covering file
    decoding, folder batch conversion, and format consistency
    - readme.md: added Tests section with run instructions
    [test_drop_logger.py, test_main.py, test_unpack_droplogger_binary.py]
2026-04-01 Improve project structure
    - Move unpack_droplogger_binary.py to project root, separating the
    desktop tool from MicroPython firmware in scripts/
    - Add scripts/config/*.txt.example files; untrack and gitignore the
    real per-device config files (device_name.txt, accel_calibration.txt)
    - Add requirements-dev.txt (pytest)
    - Update tests/conftest.py to add project root to sys.path
    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
2026-04-02 Add data evaluation notebook with sample drop test data
    Includes evaluate_droplogger.ipynb covering timing statistics, channel
    statistics, time-series plots (pressure/acceleration/rotation), sample
    rate visualisation, and sensor saturation checks. Sample CSV from a
    real drop test is included under sample-data/. requirements.txt lists
    the notebook dependencies (pandas, matplotlib, numpy, jupyter).
    [droplogger-test.csv]
2026-04-02 Add terminal velocity, tumble PSD, noise floor and write-pause analyses
    Adds four new sections to evaluate_droplogger.ipynb:
    - Terminal velocity: pressure altitude-rate plateau detection with plot
    - Tumble frequency: Welch PSD of gyro channels during freefall window
    - Pressure noise floor: std of pressure in post-landing stationary phase
    - Write-pause impact: stale-value check around write-flush pauses
    Adds scipy to desktop-tools/requirements.txt (needed for Welch PSD).
2026-04-02 Update README with notebook and models documentation
    Adds an Evaluating Data section describing evaluate_droplogger.ipynb and
    its workflow, adds the notebook and sample-data entries to the desktop
    tools file structure table, and adds a models/ table covering the 3D
    printable enclosure parts.
2026-04-02 Add test_board.py script and documentation
    - Add test_board.py: simple sensor test script for board verification
    Reads and prints pressure, accelerometer, and gyro data at 10 Hz
    - Update readme.md with testing instructions and script documentation
    - Add 'Testing New Boards' section with usage guide and success criteria
2026-04-03 Release v1.2.0: Add calibration and test scripts
2026-04-03 correct pin for user led
    [file_server.py]
2026-04-03 fix unpacker
    [droplogger-test-data.csv, droplogger-test.csv]
2026-04-06 Release v1.2.1: Fix unpacker and correct user LED pin
2026-04-24 test script for new gyro
2026-05-02 Add config-file IMU selection for ICM20649 and ISM330DHCX
    IMU type is now read from config/imu_type.txt at runtime, following the
    same pattern as device_name.txt. Falls back to ICM20649 if the file is
    missing or contains an unrecognised value.
    [drop_logger.py, main.py, test_board.py]
2026-05-02 Update readme to document ISM330DHCX support and IMU selection config
    Adds ISM330DHCX sensor specs, documents config/imu_type.txt, and updates
    the overview, hardware table, configuration, code overview, and file
    structure sections accordingly.
